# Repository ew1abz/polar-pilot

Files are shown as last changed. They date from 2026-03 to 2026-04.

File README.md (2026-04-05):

# Polar Pilot

<p align="center">
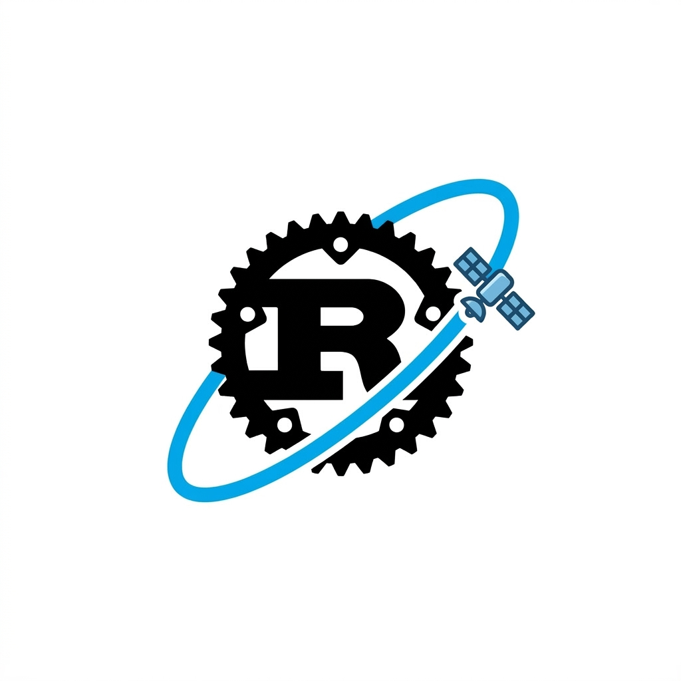
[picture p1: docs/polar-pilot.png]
Polar Pilot logo
  
</p>

<p align="center">
  <em>Bare-metal Rust firmware for a satellite antenna rotator controller — Hamlib + EasyComm II over Ethernet, live polar display, no OS.</em>
</p>

<p align="center">
  
  
  
  
</p>

<p align="center">
  <a href="https://github.com/ew1abz/polar-pilot">
    Repo card
  </a>
</p>

---

## Overview

Polar Pilot was originally designed as a controller for the
[SatNOGS rotator](https://wiki.satnogs.org/SatNOGS_Rotator_v3) — the
open-source satellite antenna rotator from the Libre Space Foundation. It has
since grown into a general-purpose two-axis rotator controller.

Polar Pilot turns an STM32L432KC Nucleo-32 board into a full-featured antenna
rotator controller. It speaks both **Hamlib rotctld** (TCP port 4533) and
**EasyComm II** (USART2 serial) so it integrates directly with
[gpredict](http://gpredict.oz9aec.net/), [Orbitron](https://www.stoff.pl/),
or any rotator-aware logging software out of the box.

Networking is handled by a W5500 hardwired TCP/IP module over SPI. A 128×64
OLED shows a live polar diagram of current and target azimuth/elevation. A
5-way navigation button lets you jog the rotator manually without a computer.

The entire firmware is `no_std` / `no_main` — no RTOS, no heap, no Linux. Nine
concurrent async tasks run on the [Embassy](https://embassy.dev/) executor.

## Features

- **Dual interface** — Ethernet (TCP :4533) and serial (USART2) operate simultaneously
- **Dual serial protocol** — EasyComm II and GS-232/GS-232B commands on the same USART2 port
- **Dual TCP connection** — up to two concurrent rotctld clients on port 4533
- **W5500 Ethernet** — ICMP (ping), DHCP, hardwired TCP/IP stack
- **[SSD1306 polar display](docs/OLED_POLAR_DISPLAY.md)** — real-time azimuth/elevation polar chart at 4 Hz
- **Stepper motor control** — hardware PWM via TIM1/TIM2, STEP/DIR/EN interface
- **[Auto-homing](docs/HOMING.md)** — endstop-based homing on power-on
- **Soft limits** — configurable AZ/EL travel limits via rotctld (`L`) and EasyComm (`LM`), persisted across commands
- **[5-way joystick](docs/MANUAL_CONTROL.md)** — manual GoTo and Stop commands without a PC
- **Heartbeat LED** — 1 Hz blink on PB3 to confirm the firmware is alive
- **Embassy async** — nine cooperative tasks, no RTOS, no heap

## Hardware

The firmware is flexible — W5500, SSD1306, stepper drivers, and the 5-way
button can each be omitted. The system boots and operates with whatever subset
is physically connected; missing peripherals are detected at runtime and their
tasks degrade gracefully without affecting the rest.

| Component | Part | Required | Notes |
|---|---|---|---|
| MCU | STM32L432KC | Yes | Cortex-M4F, 80 MHz, 256 KB flash |
| Board | Nucleo-L432KC  | Yes | Nucleo-32, ST-Link v2 onboard |
| Ethernet | W5500 module | No | Rotctld TCP server disabled if absent |
| Display | SSD1306 | No | 128×64 OLED, I2C; retries until connected |
| AZ stepper | A4988 or equiv | Yes | STEP/DIR/EN |
| EL stepper | A4988 or equiv | Yes | STEP/DIR/EN |
| Navigation | 5-way button | No | Pull-ups hold idle if unplugged  |
| Endstops | Microswitch ×2 | Yes | Homing faults without them |

### Required Nucleo board modifications

Four 0 Ω solder bridges must be removed before assembling:

| Bridge | Why |
|---|---|
| SB1 | Frees PC14 from the 32 kHz oscillator -> AZ DIR output |
| SB2 | Frees PC15 from the 32 kHz oscillator -> Nav CENTER input |
| SB16 | Isolates PA5 from PB6 so SPI1 (W5500) and I2C1 (SSD1306) don't short |
| SB18 | Isolates PA6 from PB7 for the same reason |

See [docs/SPEC.md](docs/SPEC.md) for the full pin table and a standalone-power
jumper note (needed when running without USB).

### Schematic

The KiCad schematic is in [kikad/polar-pilot.kicad_sch](kikad/polar-pilot.kicad_sch).
A rendered PDF export is at [kikad/polar-pilot.pdf](kikad/polar-pilot.pdf).

## Getting Started

### Prerequisites

```bash
rustup target add thumbv7em-none-eabihf
cargo install probe-rs-tools
```

### Build and flash

```bash
cargo build --release        # build only
cargo run --release          # build + flash + RTT console
```

### Hardware test binaries

```bash
cargo run --release --bin w5500_test    # W5500 chip version register
cargo run --release --bin oled_test     # OLED display
cargo run --release --bin motor_test    # stepper motion
cargo run --release --bin endstop_test  # endstop inputs
cargo run --release --bin button_test   # 5-way nav buttons
```

### Connecting gpredict

1. Flash the firmware and connect the W5500 module to your network.
2. Watch the LCD for the DHCP-assigned IP address.
3. In gpredict → Edit → Preferences → Interfaces → Rotators, add a new
   rotator: **Host** = `<ip>`, **Port** = `4533`.
4. Start tracking — gpredict will drive the rotator via rotctld protocol.

## Architecture

Nine Embassy async tasks communicate through two shared primitives:

```text
[rotctld TCP :4533] ──┐
[easycom USART2]  ────┤  RotatorCmd   ┌────────────┐
[5-way nav keys]  ────┴──────────────►│ motor_task ├──► Watch<RotatorState>
                                      └────────────┘
                                            │
                        ┌───────────────────┼───────────────┐
                        ▼                   ▼               ▼
                  display_task        ethernet_task      led_task
```

- **`Watch<RotatorState>`** — single-producer (motor_task), multi-consumer
  broadcast of current and target position
- **`Channel<RotatorCmd>`** — multi-producer (rotctld, easycom, keys),
  single-consumer (motor_task) command funnel

Full data-flow diagrams and per-task peripheral assignments are in
[docs/TASK_ARCHITECTURE.md](docs/TASK_ARCHITECTURE.md).

## Quality

**Memory-safe by construction.** Written in Rust — no buffer overflows, no
use-after-free, no data races. `#![no_std]` / `#![no_main]` with zero heap
allocation; every buffer is stack or statically allocated, so there is no
allocator to corrupt and no fragmentation at runtime.

**Tested at two layers.** A suite of 52 protocol tests runs against an
in-process Python stub on every CI push — no hardware required. A separate
live test suite covers DHCP/TCP connectivity, motor convergence, soft-limit
enforcement, EasyComm II, GS-232, and two concurrent TCP clients against real
hardware before every release.

**Automated CI/CD.** GitHub Actions builds the firmware on every push.
A dedicated release workflow fires on a version tag, produces `.bin` and
`.hex` artifacts, and publishes them to the GitHub Releases page automatically.

**Comprehensive documentation.**

| Document | Contents |
|---|---|
| [docs/SPEC.md](docs/SPEC.md) | Full pin table, solder-bridge modifications, protocol reference |
| [docs/TASK_ARCHITECTURE.md](docs/TASK_ARCHITECTURE.md) | Per-task data flow and peripheral assignments |
| [docs/HOMING.md](docs/HOMING.md) | Homing algorithm, fault handling, edge cases |
| [docs/MANUAL_CONTROL.md](docs/MANUAL_CONTROL.md) | 5-way joystick behaviour |
| [docs/OLED_POLAR_DISPLAY.md](docs/OLED_POLAR_DISPLAY.md) | Polar chart rendering |
| [docs/BOM.md](docs/BOM.md) | Bill of materials with datasheets and purchase links |
| [docs/DEVELOPMENT.md](docs/DEVELOPMENT.md) | Build, flash, test, and crate dependency notes |
| [docs/RELEASE_CHECKLIST.md](docs/RELEASE_CHECKLIST.md) | Step-by-step release process |
| [kikad/polar-pilot.pdf](kikad/polar-pilot.pdf) | Full schematic (KiCad PDF export) |

## Roadmap

- [ ] [540° / 1.5-rotation overtravel mode](docs/OVERTRAVEL.md) (eliminates the north-crossing dead zone)
- [ ] Single-axis (AZ-only) build via a Cargo feature flag
- [ ] Auxiliary GPIO outputs for LNA, PA, and antenna switch control
- [ ] Screen modes: polar chart / big AZ+EL digits / info (IP, version, GitHub)
- [ ] Rust TUI companion application
- [ ] Rust/WASM web companion app
- [ ] Firmware update over the network (OTA via TCP)
- [ ] RP2350 port using a board with integrated W5500
- [ ] Custom PCB with integrated PoE

## License

Copyright (C) 2026 ew1abz

This program is free software: you can redistribute it and/or modify it under
the terms of the **GNU General Public License v3.0** as published by the Free
Software Foundation.

See [LICENSE](LICENSE) for the full text.

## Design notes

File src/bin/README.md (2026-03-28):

# Hardware Tests

Standalone binaries for testing individual peripherals on the STM32L432KC
Nucleo-32 board. Each test is self-contained — no dependencies between them.

## Prerequisites

```bash
rustup target add thumbv7em-none-eabihf
cargo install probe-rs-tools
```

Connect the Nucleo board via USB. Output is via RTT (Real-Time Transfer)
shown in the `cargo run` terminal.

## Tests

### button_test — 5-way navigation switch

Polls all 5 buttons at 20 ms and logs press/release events.
LED turns on while any button is held.

**Pins**: UP=PB1, DOWN=PB0, LEFT=PA11, RIGHT=PA12, CENTER=PC15
(active-low, internal pull-up)

```bash
cargo run --release --bin button_test
```

### motor_test — AZ/EL stepper motors

Asserts motor enable (PB4 low), then drives both steppers via hardware PWM.
Toggles direction on both axes every 2 seconds. LED blinks as heartbeat.

**Pins**: AZ STEP=PA8 (TIM1), EL STEP=PA0 (TIM2), AZ DIR=PC14, EL DIR=PA9,
Motor EN=PB4 (active-low)

```bash
cargo run --release --bin motor_test
```

### oled_test — SSD1306 128x64 OLED display

Initializes the SSD1306 over I2C1, then draws a title ("Polar Pilot"),
a counter incrementing every second, and a dot cycling through 4 corners.
LED toggles each update.

**Pins**: I2C1 — PB6/SCL, PB7/SDA (address 0x3C)

```bash
cargo run --release --bin oled_test
```

### endstop_test — AZ/EL homing with endstops

Drives both steppers at 200 Hz toward home. When an endstop
triggers (active-low), that axis stops. LED blinks fast once
both axes are homed. Skips axes already at home on startup.

**Pins**: AZ STEP=PA8 (TIM1), EL STEP=PA0 (TIM2), AZ DIR=PC14,
EL DIR=PA9, Motor EN=PB4 (active-low), AZ Home=PA10, EL Home=PB5
(active-low, pull-up)

```bash
cargo run --release --bin endstop_test
```

### w5500_test — W5500 SPI Ethernet

Resets the W5500 via PA1, then reads the VERSIONR register over SPI1.
Expects `0x04`. Logs attempt count and blinks LED fast on success.

**Pins**: SPI1 (PA5/SCK, PA6/MISO, PA7/MOSI, PA4/CS), RST=PA1

```bash
cargo run --release --bin w5500_test
```

## Adding a new test

Create `src/bin/<name>.rs` with `#![no_std]`, `#![no_main]`, and an
`#[embassy_executor::main]` entry point. It will be picked up automatically
by Cargo as a separate binary target.

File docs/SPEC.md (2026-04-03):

# STM32L432 + W5500 Antenna Rotator Controller

## Overview

Bare-metal Rust firmware ("Polar Pilot") for a two-axis antenna rotator
controller. Runs on an STM32L432 Nucleo-32 board with a W5500 SPI Ethernet
module, SSD1306 OLED display, two stepper motor drivers, a 5-way navigation
button, and two homing endstops. Supports Hamlib rotctld (TCP :4533) and
EasyComm II (USART2 serial), with a polar-chart local display and automatic
homing on power-on.

## Hardware

| Component | Part | Notes |
|---|---|---|
| MCU | STM32L432KC | Cortex-M4F, 80 MHz, 256 KB flash |
| Board | Nucleo-L432KC | Nucleo-32 form factor, ST-Link v2  |
| Ethernet | W5500 | Hardwired TCP/IP, SPI interface |
| Display | SSD1306 | 128×64 OLED, I2C |
| AZ stepper | A4988 or similar | STEP/DIR/EN interface |
| EL stepper | A4988 or similar | STEP/DIR/EN interface |
| Navigation | 5-way button | UP/DOWN/LEFT/RIGHT/CENTER |
| Endstops | Microswitch ×2 | Active-low, internal pull-up |

### Pin Assignments

Four 0 Ω resistors on the Nucleo board must be removed:

| Resistor | Default | Connects | Why remove |
|---|---|---|---|
| SB1 | ON | PC14 to OSC | Free PC14 for AZ DIR (no 32k LSE) |
| SB2 | ON | PC15 to OSC | Free PC15 for Nav CENTER (no LSE) |
| SB16 | ON | PA5 ↔ PB6 | Isolate SPI1_SCK from I2C1_SCL |
| SB18 | ON | PA6 ↔ PB7 | Isolate SPI1_MISO from I2C1_SDA |

SB16/SB18 bridge the SPI1 and I2C1 pins. Without removing them, SPI1 (W5500)
and I2C1 (SSD1306) cannot operate simultaneously. See UM1956 §7.10.

| Pin  | Label | Function | Peripheral | Notes |
|---|---|---|---|---|
| PA0  | A0 | EL STEP | TIM2_CH1 | HW pulse generation |
| PA1  | A1 | W5500 RST  | GPIO output  | |
| PA3  | A2 | W5500 INT  | EXTI3 | |
| PA4  | A3 | SPI1 CS | GPIO output  | W5500 chip select |
| PA5  | A4 | SPI1 SCK | SPI1 | W5500 |
| PA6  | A5 | SPI1 MISO  | SPI1 | W5500 |
| PA7  | A6 | SPI1 MOSI  | SPI1 | W5500 |
| PA2  | A7 | USART2 TX  | USART2 (AF7) | ST-LINK virtual COM |
| PA10 | D0 | AZ Home | GPIO input | Pull-up, active-low endstop |
| PA9  | D1 | EL DIR | GPIO output  | |
| PA12 | D2 | Nav RIGHT  | GPIO input | Pull-up |
| PB0  | D3 | Nav DOWN | GPIO input | Pull-up |
| PB7  | D4 | I2C1_SDA | I2C1 | SSD1306 display |
| PB6  | D5 | I2C1_SCL | I2C1 | SSD1306 display |
| PB1  | D6 | Nav UP | GPIO input | Pull-up |
| PC14 | D7 | AZ DIR | GPIO output  | |
| PC15 | D8 | Nav CENTER | GPIO input | Pull-up |
| PA8  | D9 | AZ STEP | TIM1_CH1 | HW pulse generation |
| PA11 | D10 | Nav LEFT | GPIO input | Pull-up |
| PB5  | D11 | EL Home | GPIO input | Pull-up, active-low endstop |
| PB4  | D12 | Motor EN | GPIO output  | Shared stepper EN, active-low |
| PB3  | D13 | Heartbeat  | GPIO output  | Onboard LED (LD3) |
| PA15 | — | USART2 RX  | USART2 (AF3) | ST-LINK VCP, not on headers |

**Peripherals used:** SPI1 (W5500), I2C1 (SSD1306), USART2 (serial/EasyComm),
TIM1 (AZ step), TIM2 (EL step), TIM15 (Embassy time driver), RNG,
DMA1_CH2/CH3 (SPI RX/TX), DMA1_CH6/CH7 (USART2 RX/TX).

### Standalone Operation (No USB)

When powered from an external 3.3 V supply without a USB cable, the ST-LINK
section is unpowered and its nRST output holds the MCU in reset indefinitely.

**Fix**: bridge **CN2 pin 4** (ST-LINK VDD, 3.3 V) to **CN4 pin 14** (main
3.3 V rail) with a jumper wire. This keeps the ST-LINK powered, releases
nRST, and the MCU boots normally without USB.

> CN2 is the 4-pin SWD debug connector; CN4 is the right-side morpho header.

## Software Architecture

### Tasks

See `docs/TASK_ARCHITECTURE.md` for detailed data flow diagrams and
per-task peripheral assignments. Summary:

1. **main** — Inits clocks (80 MHz), peripherals, spawns all tasks, then idles.
2. **ethernet_task** — Pumps W5500 SPI driver (embassy-net-wiznet Runner).
3. **net_task** — Drives TCP/IP stack (DHCP, ARP, timers).
4. **dhcp_watchdog_task** — Waits 120 s for DHCP; falls back to static IP.
5. **motor_task** — Receives commands, slews steppers via TIM1/TIM2 PWM,
   runs homing sequence on power-on, publishes state.
6. **display_task** — Renders polar diagram + status on SSD1306 OLED at 4 Hz.
7. **key_task** — Debounces 5-way nav buttons at 20 ms, sends GoTo/Stop commands.
8. **rotctld_task** — TCP server on :4533, Hamlib rotctld protocol subset.
9. **easycom_task** — USART2 serial, EasyComm II protocol.
10. **led_task** — PB3 heartbeat at 1 Hz.

### Network Configuration

- **DHCP client**: Enabled. Falls back to static IP after 120 s if no offer arrives.
- **Static fallback**: `192.168.1.200/24`, gateway `192.168.1.1`
  (configurable at the top of `src/tasks/net.rs`).
- **MAC address**: Locally-administered, hardcoded (`02:00:00:00:00:01`).
- **Listen port**: 4533 (TCP).

## Rotctld Protocol (Hamlib)

The device implements a subset of the rotctld text protocol. Each command is
a single line terminated by `\n`. Responses are also newline-terminated.

Up to **2 concurrent TCP clients** are supported simultaneously on port 4533.

### Supported Commands

| Command | Alias | Description | Response |
|---|---|---|---|
| `p` | `\get_pos` | Get position | `<az>\n<el>\n` |
| `P <az> <el>` | `\set_pos <az> <el>` | Set position | `RPRT 0\n` |
| `S` | `\stop` | Stop rotation | `RPRT 0\n` |
| `l` | `\get_limits` | Get soft limits | `az_min\naz_max\nel_min\nel_max\nRPRT 0\n` |
| `L <az_min> <az_max> <el_min> <el_max>` | `\set_limits …` | Set soft limits | `RPRT 0\n` |
| `q` | `\quit` | Close connection | (connection closed) |
| `_` | `\get_info` | Get info | `Model: Polar Pilot\n` |
| `\dump_state` | — | Hamlib compatibility | State block with current limits |

When `Phase::Fault`, `p`, `P`, and `S` all respond with:

```text
FAULT: <message>
RPRT -9
```

`RPRT -9` is Hamlib's "command rejected" code. Unrecognized commands return `RPRT -1\n`.

### `\dump_state` Response

The `min_az/max_az/min_el/max_el` fields reflect the current soft limits:

```text
0
rot_model=0
min_az=<az_min>
max_az=<az_max>
min_el=<el_min>
max_el=<el_max>
0
0
```

## EasyComm II Protocol

Line endings: CR, LF, or CR+LF are all accepted.

| Command | Standard  | Description | Response |
|---|---|---|---|
| `AZ` | EasyComm  | Query position | `AZ<az> EL<el>\n` |
| `AZ<az> EL<el>` | EasyComm  | Set both axes | (none) |
| `SA` / `SE` / `SA SE` | EasyComm  | Stop AZ / EL / both | (none) |
| `LM` | EasyComm  | Get soft limits | `LM az_min az_max el_min el_max\n` |
| `LM <az_min> <az_max> <el_min> <el_max>`  | EasyComm  | Set soft limits | (none) |
| `VE` | EasyComm  | Version query | `Polar Pilot v<ver>\n` |
| `RS` | EasyComm  | Park to 0/0 (no homing)  | (none) |
| `RH` | EasyComm  | Re-home (endstop search) | (none) |
| `C` | GS-232 | Query position | `AZ<az> EL<el>\n` |
| `A<NNN>` | GS-232 | Set azimuth only | (none) |
| `E<NNN>` | GS-232 | Set elevation only | (none) |
| `W <az> <el>` | GS-232B | Set both axes | (none) |
| `?` | -- | Keep-alive | `\r` |

## Development

Build instructions, flash commands, hardware test binaries, known issues, and
the protocol test suite are documented in [docs/DEVELOPMENT.md](DEVELOPMENT.md).

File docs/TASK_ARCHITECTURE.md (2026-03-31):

# Polar Pilot — Task Architecture

## Overview

The firmware runs as a set of cooperative async tasks on the Embassy executor.
All tasks share a single thread (Cortex-M4 has no OS) and yield at `.await`
points. Communication between tasks uses lock-free Embassy synchronization
primitives.

## Shared State

### `STATE` — Watch

`Watch<CriticalSectionRawMutex, RotatorState, 4>`

Single-producer (motor_task), multi-consumer broadcast of current state.

```rust
struct RotatorState {
    target_az:  f32,   // commanded azimuth   (degrees)
    target_el:  f32,   // commanded elevation (degrees)
    current_az: f32,   // virtual position from step accumulator
    current_el: f32,   // virtual position from step accumulator
    moving:     bool,  // true while any axis is slewing
    link_up:    bool,  // (reserved, always false — IP read directly from Stack)
    phase:      Phase, // Homing | Running | Fault(&'static str)
}
```

Writers call `STATE.sender().send(state)` — non-blocking, overwrites.
Readers call `STATE.try_get()` — returns the latest value without blocking.

### `CMD` — Channel

`Channel<CriticalSectionRawMutex, RotatorCmd, 4>`

Multi-producer command funnel into motor_task.

```rust
enum RotatorCmd {
    GoTo { az: f32, el: f32 },
    Stop,
}
```

Producers: rotctld_task, easycom_task, key_task.
Consumer: motor_task (clamped to LIMITS before applying).

### `LIMITS` — Mutex

`Mutex<CriticalSectionRawMutex, Cell<SoftLimits>>`

Operator-configurable travel limits. Read by motor_task on every GoTo;
written by rotctld_task (`L`) and easycom_task (`LM`). Defaults to
AZ 0–360°, EL 0–180°. Resets to defaults on power cycle.

## Task Map

```text
                       ┌──────────────┐
                       │     main     │
                       │  (init only) │
                       └──────┬───────┘
                              │ spawns all tasks
      ┌──────┬──────┬─────────┼──────┬────────┬──────┬──────┐
      ▼      ▼      ▼         ▼      ▼        ▼      ▼      ▼
  ┌──────┐ ┌────┐ ┌──────┐ ┌──────┐ ┌──────┐ ┌────┐ ┌────┐ ┌────┐
  │motor │ │disp│ │ key  │ │rotcld│ │easyco│ │eth │ │net │ │led │
  │ task │ │ lay│ │ task │ │  task│ │m task│ │task│ │task│ │task│
  └──────┘ └────┘ └──────┘ └──────┘ └──────┘ └────┘ └────┘ └────┘
      │        ▲      │         │        │
      │ STATE  │      │   CMD   │        │   LIMITS
      ▼        │      ▼         ▼        ▼
  ┌───────┐    │  ┌──────────────────────────┐
  │ Watch │────┘  │     Command Channel      │
  │(STATE)│◄──────│       (RotatorCmd)       │
  └───────┘       └──────────────────────────┘

  Also spawned:
  ┌─────────────────┐
  │ dhcp_watchdog   │  waits 120 s, then sets static IP via Stack
  └─────────────────┘
```

## Task Descriptions

### 1. main (init only)

- Configures clocks (80 MHz HSI+PLL)
- Initializes all peripherals: SPI1, I2C1, USART2, TIM1, TIM2, GPIOs, RNG
- Creates W5500 driver, embassy-net stack
- Publishes initial `RotatorState::default()` to STATE
- Spawns all tasks, then returns (idles)

**Peripherals consumed**: all — parceled out to tasks via ownership transfer.

### 2. ethernet_task

- Runs the `embassy-net-wiznet` W5500 Runner
- Pumps SPI frames between the W5500 and the network stack

**Peripherals**: SPI1 (PA4–PA7, DMA1_CH2/CH3), W5500 INT (PA3), W5500 RST (PA1)

### 3. net_task

- Runs `embassy_net::Stack::run`
- Handles DHCP, ARP, ICMP, TCP timers

**Peripherals**: none directly (operates on the Stack)

### 4. dhcp_watchdog_task

- Calls `stack.wait_config_up()` with a 120 s timeout
- On timeout: calls `stack.set_config_v4(Static(...))` with the predefined
  fallback address (`192.168.1.200/24`)
- After resolving (either way), sleeps indefinitely

**Peripherals**: none (operates on the Stack)

### 5. motor_task

**Purpose**: homing, position tracking, stepper control.

**Homing (runs once at power-on):**

1. Publishes `Phase::Homing`
2. AZ axis: back-off if already on endstop (3 s timeout → `Fault`), then
   approach in negative direction until endstop asserts (95 s limit → `Fault`).
   Sets `current_az = 0`, `target_az = 0`.
3. EL axis: same sequence (28 s limit).
4. Publishes `Phase::Running`.

On any homing fault: disables motor driver, publishes
`Phase::Fault("AZ endstop stuck" | "AZ travel limit" | …)`, loops forever.

**Normal operation loop (1 ms tick):**

- Receives `RotatorCmd` from CMD channel (with 1 ms timeout)
- GoTo: clamps targets to LIMITS, then updates target_az/target_el
- Stop: sets targets to current position
- Advances virtual position each tick using step accumulator:
  `steps = floor(elapsed_us × STEP_HZ / 1_000_000)` — fractional remainder
  carries forward to prevent truncation drift
- Enables/disables TIM1 (AZ) and TIM2 (EL) PWM based on whether axis is moving
- Hardware endstop safety: if endstop asserts while moving toward home,
  zeroes position and stops PWM
- Software limits: AZ lower limit removed (allows wrap through north);
  AZ upper 360° and EL 0°/180° limits stop PWM and reset target
- Motor enable pin (PB4) driven low while moving, high when idle
- Publishes RotatorState every tick

**Motor parameters** (in `src/tasks/motor.rs`):

| Parameter | Value |
|---|---|
| STEP_HZ | 4000 Hz |
| STEPS_PER_REV  | 200 (full step) |
| GEAR_RATIO | 54:1 |
| AZ_MICROSTEPS  | 32 |
| EL_MICROSTEPS  | 32 |
| MOTOR_TICK | 1 ms |

**Peripherals**: TIM1 (PA8), TIM2 (PA0), GPIO out (PC14 AZ DIR, PA9 EL DIR,
PB4 motor EN), GPIO in (PA10 AZ home, PB5 EL home)

### 6. display_task

**Purpose**: render the polar diagram and status on the SSD1306 OLED.

- Receives `Stack` handle for direct IP/link-status queries via `config_v4()`
- Redraws at 4 Hz (250 ms Ticker)
- Fault screen: full-panel text (`FAULT` / message / `Power cycle` / `to reset`)
- Normal screen: polar rings, crosshair, cardinal labels (N/S/E/W),
  airplane marker at current az/el, AZ/EL readout, status, IP address
- IP shown split across two rows: `A.B.` / `C.D`, or `---.---.` / `---.---`
  while waiting for DHCP
- Status line: `Homing` / `Moving` / `Idle` / `No IP`

See [OLED_POLAR_DISPLAY.md](OLED_POLAR_DISPLAY.md) for rendering details.

**Peripherals**: I2C1 (PB6 SCL, PB7 SDA) — blocking 100 kHz

**Note**: blocking I2C flush (~92 ms per frame) is compensated by motor_task's
elapsed-time step accumulator — virtual position tracks physical motion
regardless of display task scheduling delays.

### 7. key_task

**Purpose**: read the 5-way navigation button and send commands.

- Scans 5 GPIO inputs: UP (PB1), DOWN (PB0), LEFT (PA11), RIGHT (PA12),
  CENTER (PC15)
- Debounce: 20 ms poll, require 2 consecutive identical reads
- Button actions:
  - **UP**: jog AZ positive (sentinel target +9999°, motor limits enforce stop)
  - **DOWN**: jog AZ negative (sentinel target −9999°)
  - **RIGHT**: jog EL positive (sentinel target +9999°)
  - **LEFT**: jog EL negative (sentinel target −9999°)
  - **CENTER press**: park both axes to AZ 0° / EL 0°
- Release any jog button → `RotatorCmd::Stop`
- Simultaneous AZ + EL buttons combined into one GoTo per tick
- All input ignored when `phase != Phase::Running`

**Peripherals**: GPIO input pull-up (PB1, PB0, PA11, PA12, PC15)

### 8. rotctld_task

**Purpose**: Hamlib rotctld TCP server.

- Binds TCP socket on port 4533; accepts one connection at a time
- 30 s inactivity timeout per connection
- Checks `Phase::Fault` on every command — returns `FAULT: <msg>\nRPRT -9\n`
- Supported commands: `p`/`\get_pos`, `P`/`\set_pos`, `S`/`\stop`,
  `l`/`\get_limits`, `L`/`\set_limits`, `q`/`\quit`, `_`/`\get_info`,
  `\dump_state`
- `\dump_state` reflects current LIMITS values

**Peripherals**: none (embassy-net TCP socket)

### 9. easycom_task

**Purpose**: EasyComm II serial interface.

- USART2 RX (PA15), TX (PA2) — 9600 baud, DMA
- Connected to ST-LINK VCP (appears as `/dev/ttyACM0`)
- Supported commands: `AZ`/`AZ<n> EL<n>`, `SA`/`SE`/`SA SE`, `VE`,
  `LM` (get limits), `LM <az_min> <az_max> <el_min> <el_max>` (set limits)

**Peripherals**: USART2 TX (PA2, AF7), USART2 RX (PA15, AF3),
DMA1_CH7 (TX), DMA1_CH6 (RX)

### 10. led_task

- Toggles PB3 (onboard LED) at 1 Hz as heartbeat
- `Ticker::every(Duration::from_secs(1))`

**Peripherals**: GPIO out (PB3)

## Data Flow Summary

```text
 [rotctld TCP]──┐
 [easycom UART]─┤  RotatorCmd      ┌─────────────┐  STATE   ┌──────────┐
 [5-way keys]───┴─────────────────►│ motor_task  ├─────────►│ display  │
                                   │             │          └──────────┘
                RotatorCmd         │ TIM1+TIM2   │  STATE   ┌──────────┐
  LIMITS ──────────────────────────│ endstops    ├─────────►│ rotctld  │
  (read on GoTo)                   └─────────────┘          └──────────┘
                                                   STATE   ┌──────────┐
                                                 ─────────►│ easycom  │
                                                           └──────────┘
```

- **Commands** flow in from three sources via CMD channel
- **State** flows out from motor_task via STATE watch to all readers
- **LIMITS** are written by rotctld/easycom, read by motor_task on GoTo
- **IP/link status** read directly from Stack by display_task (not via STATE)

## Resource Budget

| Resource | Usage |
|---|---|
| Flash (256 KB) | ~80–100 KB with display + networking + fonts |
| RAM (64 KB) | 1 KB OLED framebuf + ~8 KB net buffers + task stacks  |
| DMA channels | DMA1_CH2 (SPI RX), CH3 (SPI TX), CH6 (UART RX), CH7 (UART TX) |
| Timers | TIM1 (AZ step), TIM2 (EL step), TIM15 (Embassy time)  |
| I2C | I2C1 (SSD1306, 100 kHz blocking) |
| SPI | SPI1 (W5500, 1 MHz async) |
| USART | USART2 (EasyComm, 9600 baud) |
| Embassy tasks | 10 concurrent |

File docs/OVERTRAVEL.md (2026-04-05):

# 1.5 Rotation (540° Overtravel)

> **Status: Not implemented.** This is a planned feature. See the Roadmap in
> [README.md](../README.md).

## Overview

Adding overtravel (540° rotation) eliminates the "dead zone" at 0°/360° north.
High-end commercial and amateur rotators use this approach to avoid forced
unwinds during satellite passes that cross the north mark.

With a standard 360° rotator, a satellite crossing 0° north forces an
immediate full-circle unwind. With a 540° rotator (0° to 540°), that same
pass can be tracked from 350° through 0° all the way to 180° before hitting a
physical limit — cutting required unwinds significantly.

## What Needs to Change

### 1. Mechanical

- **Cable service loop** — the coax must have enough slack to handle 540° of
  twist without tensioning connectors or rubbing against sharp edges.
- **Soft limits** — azimuth range extended from `0–360°` to `0–540°`.

### 2. Firmware Logic (The Overlap)

The azimuth range maps to physical angles as follows:

| Range | Physical angle |
|---|---|
| 0° – 180° | Primary range |
| 180° – 360° | Secondary range |
| 360° – 540° | Overlap (same as 0° – 180°) |

`motor_task` needs to track raw stepper position across the 360° boundary
without wrapping, and the soft-limit enforcement must accept `max_az` up to
540°.

### 3. Host Software (Hamlib / rotctld)

gpredict does not know the rotator can go past 360° without explicit
configuration. Pass the extended range to rotctld with `-m` / `-M`:

```bash
rotctld -m 0 -M 540 -model [YOUR_MODEL_ID]
```

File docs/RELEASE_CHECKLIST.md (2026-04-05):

# Release Checklist — Polar Pilot

Steps to cut an official release. The GitHub Actions release workflow
(`release.yml`) triggers automatically on a `v*.*.*` tag push and produces
`.bin` and `.hex` artifacts. Everything before that tag is manual.

---

## 1. Code

- [ ] All planned features for this release are merged to `main`
- [ ] No `TODO` / `FIXME` comments left for known blockers
- [ ] `Cargo.toml` version bumped (`version = "x.y.z"`)
- [ ] `Cargo.lock` committed (ensure reproducible builds)

## 2. Protocol Tests (Stub)

Run the full stub suite — no hardware required:

```bash
python3 -m pytest tests/test_protocol.py -v
```

- [ ] All 52 stub tests pass

## 3. Live Hardware Tests

Flash the firmware and run against real hardware:

```bash
cargo run --release

ROTATOR_HOST=<ip> ROTATOR_PORT=/dev/ttyUSB0 \
  python3 -m pytest tests/ -v --timeout=120 --override-ini="addopts="
```

- [ ] DHCP lease acquired (or static fallback at `192.168.1.200`)
- [ ] `p` returns valid AZ/EL from a cold boot
- [ ] `P <az> <el>` drives both axes to target
- [ ] Soft limits enforced (`L` / `LM` set, out-of-range `P` clamped)
- [ ] Two concurrent TCP clients connect simultaneously on port 4533
- [ ] EasyComm II commands work over USART2 (`AZ`, `AZ<n> EL<n>`, `SA`, `SE`, `VE`)
- [ ] GS-232 commands work (`C`, `A<nnn>`, `E<nnn>`, `W <az> <el>`)
- [ ] Homing sequence completes on power-on (both endstops triggered)
- [ ] All live + slow tests pass

## 4. Hardware Test Binaries

Verify each peripheral individually:

```bash
cargo run --release --bin w5500_test
cargo run --release --bin oled_test
cargo run --release --bin motor_test
cargo run --release --bin endstop_test
cargo run --release --bin button_test
```

- [ ] W5500 chip version register reads correctly
- [ ] OLED polar chart renders without artifacts
- [ ] Stepper motors sweep AZ and EL
- [ ] Both endstops register active-low transitions
- [ ] All five nav buttons register correctly

## 5. Documentation

- [ ] `docs/SPEC.md` reflects current pin assignments and hardware table
- [ ] `README.md` features list matches implemented functionality
- [ ] `docs/BOM.md` part list and links are current

## 6. Tag and Push

```bash
git tag v<x.y.z>
git push origin main --tags
```

- [ ] Tag pushed — GitHub Actions `release.yml` starts automatically
- [ ] CI build passes (check Actions tab)
- [ ] Release page shows `.bin` and `.hex` artifacts attached
- [ ] Auto-generated release notes look reasonable; edit if needed

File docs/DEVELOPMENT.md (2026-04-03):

# Polar Pilot — Development Notes

## Prerequisites

```bash
rustup target add thumbv7em-none-eabihf
cargo install probe-rs-tools       # only needed for flashing
```

Python 3.10+ is required for the protocol test suite:

```bash
python3 -m pip install pytest pytest-timeout   # stub + rotctld live tests
python3 -m pip install pyserial                # EasyComm live tests only
```

## Build

```bash
cargo build --release
```

## Flash + RTT Log

```bash
cargo run --release
```

Configured via `.cargo/config.toml` to call `probe-rs run --chip STM32L432KCUx`.

## Hardware Test Binaries

Standalone binaries in `src/bin/` exercise individual peripherals in isolation.
Flash them the same way as the main firmware:

```bash
cargo run --release --bin w5500_test    # W5500 chip version + link status
cargo run --release --bin button_test   # 5-way nav button read-out
cargo run --release --bin motor_test    # stepper sweep
cargo run --release --bin oled_test     # OLED polar chart render
cargo run --release --bin endstop_test  # endstop state over RTT
```

## Testing

### Overview

There are two testing layers:

| Layer | Runs in | Requires hardware |
|---|---|---|
| Protocol tests (`tests/test_protocol.py`) | CI and locally | No |
| Live hardware tests (`tests/test_live.py`) | Manually, pre-release | Yes |

The protocol tests run against an in-process Python TCP stub (`tests/stub_server.py`)
that mirrors the firmware's rotctld dispatch table.  The stub's state is a plain
Python object set directly in each test fixture — no sleeping, no timing, no motor
physics.

### Running Protocol Tests (Stub)

```bash
python3 -m pytest                         # uses pytest.ini defaults (excludes live tests)
python3 -m pytest tests/test_protocol.py  # explicit
```

52 tests covering all commands, argument errors, protocol robustness
(pipelining, split TCP segments, CRLF line endings, oversized lines).

### Running Live Hardware Tests

Set `ROTATOR_HOST` to the device's IP address (DHCP-assigned or static fallback
`192.168.1.200`):

The default `pytest.ini` excludes live tests with `-m "not live"`.  Pass
`-m live` (or `-m "live or slow"` to include motor-movement tests) to
override it:

```bash
# rotctld (TCP)
ROTATOR_HOST=192.168.1.42 python3 -m pytest tests/test_live.py -v --timeout=60 -m live

# EasyComm II (serial) -- requires pyserial and a USB-serial adapter on USART2
ROTATOR_PORT=/dev/ttyUSB0 python3 -m pytest tests/test_easycom.py -v --timeout=60 -m live

# Include slow motor-movement tests
ROTATOR_HOST=192.168.1.42 python3 -m pytest tests/test_live.py -v --timeout=60 -m "live or slow"

# Both together
ROTATOR_HOST=192.168.1.42 ROTATOR_PORT=/dev/ttyUSB0 python3 -m pytest tests/ -v --timeout=60 -m "live or slow"

# All 87 tests (stub + live + slow) -- overrides the default -m "not live" in pytest.ini
ROTATOR_HOST=192.168.1.42 ROTATOR_PORT=/dev/ttyUSB0 python3 -m pytest tests/ -v --timeout=120 --override-ini="addopts="

# List all tests without running them
python3 -m pytest tests/ --collect-only -q --override-ini="addopts="
```

Live tests cover DHCP/TCP connectivity, motor convergence to target, stop
response, reset/park, soft limit enforcement, and two concurrent clients.

### Test File Layout

```text
tests/
  stub_server.py      in-process TCP stub + RotatorState
  conftest.py         conn_stub (per-test clean state) and conn_live fixtures
  test_protocol.py    52 protocol tests against stub
  test_live.py        hardware tests, skipped unless ROTATOR_HOST is set
pytest.ini            marks live/slow; excludes live tests from default run
```

### Notes on Protocol Behaviour Under Test

- **Unknown commands** return `RPRT -8` (RIG_ENIMPL).
- **Invalid arguments** (wrong count, non-numeric) return `RPRT -1` (RIG_EINVAL).
- **`w`/`\send_cmd`** returns `RPRT -1` — no backend pass-through target exists.
- **Empty or whitespace-only lines** return `RPRT -8` and do not crash the server.
- **`P` with out-of-limit coordinates** is silently clamped by `motor_task` —
  the TCP layer returns `RPRT 0` and the motor stops at the limit.
- **Line buffer** is 128 bytes; lines longer than this close the connection.

## Crate Dependencies

| Crate | Purpose |
|---|---|
| `embassy-executor` | Async task executor |
| `embassy-stm32` | HAL for STM32L4 (SPI, I2C, GPIO, …) |
| `embassy-time` | Timekeeping (TIM15 driver, Ticker) |
| `embassy-sync` | Watch + Channel + Mutex for inter-task comms |
| `embassy-net` | TCP/IP stack (TCP, DHCPv4) |
| `embassy-net-wiznet` | W5500 driver for embassy-net |
| `embedded-hal-bus` | SPI ExclusiveDevice wrapper |
| `embedded-io-async`  | Async I/O traits (Write::write_all) |
| `ssd1306` | SSD1306 OLED driver |
| `embedded-graphics`  | 2D drawing primitives for OLED |
| `heapless` | Fixed-capacity String/Vec (no alloc) |
| `libm` | Software float math (sinf, cosf) |
| `defmt` + `defmt-rtt`| Logging via RTT (non-blocking) |
| `panic-reset` | Reset on panic — safe for standalone |
| `static_cell` | One-time `'static` init for task data  |
| `cortex-m` / `cortex-m-rt` | Runtime + vector table |

## Binary Size

Release build (`opt-level = "s"`, LTO):

| Configuration | .text (bytes) | Delta |
|---|---|---|
| Minimal (TCP + static IP, no defmt)  | 42,312 | baseline |
| Minimal (TCP + static IP, defmt) | 66,384 | +24,072 (+56.9%) |
| + DHCP | 75,672 | +33,360 (+78.8%) |
| + DHCP + ICMP echo reply | 78,112 | +35,800 (+84.6%) |

STM32L432KC has 256 KB flash. The `minimal` branch has static-IP-only builds
for reference.

## Project Structure

```text
.
├── .cargo/config.toml              # target, runner, DEFMT_LOG
├── .github/workflows/ci.yml        # CI: build + protocol tests
├── build.rs                        # memory.x linker script setup
├── memory.x                        # Flash/RAM layout for STM32L432
├── Cargo.toml
├── pytest.ini
├── tests/                          # rotctld protocol test suite (Python)
├── src/
│   ├── main.rs                     # peripheral init, task spawning
│   ├── types.rs                    # RotatorState, RotatorCmd, Phase, SoftLimits, statics
│   ├── util.rs                     # parse_f32, parse_f32_bytes, line helpers
│   ├── tasks/
│   │   ├── motor.rs                # motor_task — homing, slewing, endstops
│   │   ├── display.rs              # display_task — SSD1306 polar chart
│   │   ├── keys.rs                 # key_task — 5-way button
│   │   ├── rotctld.rs              # rotctld_task — TCP :4533
│   │   ├── easycom.rs              # easycom_task — USART2 EasyComm II
│   │   └── net.rs                  # ethernet_task, net_task, led_task, dhcp_watchdog_task
│   └── bin/                        # standalone hardware test binaries
│       ├── w5500_test.rs
│       ├── button_test.rs
│       ├── motor_test.rs
│       ├── oled_test.rs
│       └── endstop_test.rs
├── docs/
│   ├── SPEC.md                     # hardware spec and protocol reference
│   ├── DEVELOPMENT.md              # this file
│   ├── TASK_ARCHITECTURE.md        # task data flow and peripheral map
│   ├── OLED_POLAR_DISPLAY.md       # OLED rendering details
│   ├── HOMING.md                   # homing algorithm and fault handling
│   ├── MANUAL_CONTROL.md           # 5-way button behaviour
│   ├── MIGRATION_NOTES.md          # comparison with rust-l432-rotator
│   ├── TODO.md                     # known gaps and planned work
│   └── EEPROM_EMULATION.md         # (future) persistent configuration
```

## Known Issues & Workarounds

### STM32L432 Fixed DMA Channel Mapping

The STM32L432 has no DMAMUX — DMA channels are hardwired per peripheral.
SPI1 must use DMA1_CH2 (RX) and DMA1_CH3 (TX); USART2 must use DMA1_CH7 (TX)
and DMA1_CH6 (RX). Using wrong channels causes silent failures.

## Constraints & Decisions

- **No `std`** — bare-metal `#![no_std]`, `#![no_main]`.
- **No heap** — all buffers are stack-allocated or static.
- **Single TCP connection** — the W5500 has 8 sockets but one is sufficient
  for rotctld; keeps the code simple.
- **No TLS** — rotctld is plaintext.

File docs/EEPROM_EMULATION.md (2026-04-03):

# EEPROM Emulation — Persistent Configuration Storage

## Status: Potential Feature

## Motivation

The rotator currently loses all configuration on power cycle. Persisting the
following would improve usability:

- Park position (AZ/EL degrees)
- Soft limits (min/max AZ, min/max EL)
- Network config override (static IP, port)
- Steps-per-degree calibration for each axis
- Last known position (for resume without homing)

## Hardware Constraints

The STM32L432KC has **no dedicated data EEPROM**. The L432 only has 256 KB of
main flash, organized as 2 KB pages. Flash endurance is ~10,000 erase cycles
per page (datasheet §3.10).

Embassy-stm32's `Flash` driver implements the `embedded-storage` `NorFlash`
and `ReadNorFlash` traits, which provides the foundation for emulation.

## Solution: `sequential-storage` on Main Flash

[`sequential-storage`](https://crates.io/crates/sequential-storage) is a
`no_std`, heap-free crate that provides a wear-leveled key-value map on top of
any `NorFlash` implementation. It distributes writes across a configurable
range of flash pages so no single page absorbs all the erase cycles.

### Flash Layout

Allocate the last 4 pages (8 KB) of flash for storage, keeping them out of
the linker's program region:

```text
0x0800_0000  ┌──────────────────────┐
             │  Firmware (≤248 KB)  │
0x0803_E000  ├──────────────────────┤  ← storage start
             │  Page 62  (2 KB)     │
             │  Page 63  (2 KB)     │
             │  Page 64  (2 KB)     │
             │  Page 65  (2 KB)     │
0x0804_0000  └──────────────────────┘  ← end of flash
```

Reserve those pages in `memory.x` so the linker never places code there:

```text
/* memory.x */
MEMORY
{
  FLASH : ORIGIN = 0x08000000, LENGTH = 248K   /* was 256K */
  STORAGE : ORIGIN = 0x0803E000, LENGTH = 8K
  RAM   : ORIGIN = 0x20000000, LENGTH = 48K
}
```

### Dependencies

```toml
# Cargo.toml
[dependencies]
sequential-storage = { version = "4", default-features = false }
embedded-storage = "0.3"
```

### Key Definitions

Define all storable keys as a compact enum. Each variant serializes to a
single `u8` discriminant — the key used in the flash map.

```rust
#[repr(u8)]
#[derive(Clone, Copy, PartialEq, Eq)]
pub enum CfgKey {
    ParkAz      = 0,
    ParkEl      = 1,
    MinAz       = 2,
    MaxAz       = 3,
    MinEl       = 4,
    MaxEl       = 5,
    StepsPerDegAz = 6,
    StepsPerDegEl = 7,
    LastAz      = 8,
    LastEl      = 9,
}
```

Values are stored as raw `f32` bytes (4 bytes each).

### Storage Helper

```rust
use embassy_stm32::flash::{Flash, WRITE_SIZE};
use sequential_storage::map;

const STORAGE_RANGE: core::ops::Range<u32> = 0x0803_E000..0x0804_0000;

/// Read one f32 config value; returns `default` if not yet written.
pub async fn cfg_read(flash: &mut Flash<'_>, key: CfgKey, default: f32) -> f32 {
    let mut buf = [0u8; 4];
    match map::fetch_item::<_, _, _>(
        flash,
        STORAGE_RANGE.clone(),
        &mut [0u8; 64],   // scratch buffer
        key as u8,
        &mut buf,
    )
    .await
    {
        Ok(Some(bytes)) => f32::from_le_bytes(bytes.try_into().unwrap_or([0u8; 4])),
        _ => default,
    }
}

/// Write one f32 config value.
pub async fn cfg_write(flash: &mut Flash<'_>, key: CfgKey, value: f32) {
    let bytes = value.to_le_bytes();
    map::store_item::<_, _, _>(
        flash,
        STORAGE_RANGE.clone(),
        &mut [0u8; 64],   // scratch buffer
        key as u8,
        &bytes,
    )
    .await
    .ok();  // best-effort; log via defmt in production
}
```

### Integration with motor_task

Load calibration at startup before spawning the motor task:

```rust
// In main(), after Flash is initialized:
let mut flash = Flash::new(p.FLASH, Irqs);

let steps_az = cfg_read(&mut flash, CfgKey::StepsPerDegAz, 400.0).await;
let steps_el = cfg_read(&mut flash, CfgKey::StepsPerDegEl, 400.0).await;
let park_az  = cfg_read(&mut flash, CfgKey::ParkAz, 0.0).await;
let park_el  = cfg_read(&mut flash, CfgKey::ParkEl, 0.0).await;

spawner.spawn(motor_task(/* ... */ steps_az, steps_el, park_az, park_el)).unwrap();
```

Save position periodically from motor_task (e.g., after each completed slew):

```rust
// Inside motor_task, after slew completes:
cfg_write(&mut flash, CfgKey::LastAz, state.az).await;
cfg_write(&mut flash, CfgKey::LastEl, state.el).await;
```

### Sharing Flash Between Tasks

`embassy-stm32`'s Flash is not `Send`-shareable by default. Options:

1. **Single owner** — pass flash into a dedicated `config_task` and send
   read/write requests via a small channel. Simplest and safest.
2. **Mutex** — wrap in `embassy_sync::mutex::Mutex<CriticalSectionRawMutex, Flash>`,
   share via static. Works but flash ops block interrupt-driven tasks briefly.

Option 1 is recommended for this project since config changes are infrequent.

## Wear Budget

With 4 pages and `sequential-storage`'s wear leveling, each logical key-value
write consumes roughly `1 / (page_count × items_per_page)` of the total erase
budget. At 10,000 cycles × 4 pages and ~10 bytes per entry:

- ~3,200 items per erase cycle sweep
- A write every 10 seconds → **>10 years** before page exhaustion

Writing `LastAz`/`LastEl` after every 100 ms position tick would exhaust flash
in ~1 year — write only on slew completion or on idle timeout.

## Open Questions

- Should static IP config be in flash or hardcoded / provisioned via serial?
- Is resume-without-homing safe? (Position could be stale after manual
  movement with power off.)
- The `Flash` peripheral conflicts with in-application firmware update (IAP)
  — if OTA is added later, the storage region layout must be coordinated.

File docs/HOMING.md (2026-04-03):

# Polar Pilot — Homing Procedure

## Purpose

Homing establishes the zero-degree reference for both axes using active-low
endstop switches. Until homing completes, reported positions are meaningless
and `GoTo` commands are rejected. The `Phase` field in `RotatorState` signals
the current state to all consumers (display, rotctld, easycom).

## When Homing Runs

| Trigger | Description |
|---|---|
| **Power-on** | Runs automatically before any command is accepted |
| **Long-press CENTER** (>500 ms) | Operator-initiated re-home from `key_task` |

Re-homing sends a dedicated `RotatorCmd::Home` (to be added alongside
`GoTo`/`Stop`). `motor_task` drops any in-progress slew and restarts the
sequence.

## Phase Enum

```rust
pub enum Phase {
    Homing,   // homing in progress — commands queued but not executed
    Running,  // homed and operational
}
```

Published in every `RotatorState` send so all tasks can react.

## Axis Sequence

Axes are homed **serially**: AZ first, then EL. Both axes use identical logic.

```text
Phase::Homing published ──────────────────────────────────────────────────►
                                                            Phase::Running
  ┌──────────────┐   ┌──────────────┐   ┌──────────────┐
  │  Pre-check   │──►│   Approach   │──►│    Settle    │
  │  (back-off   │   │  (seek home) │   │  zero pos.   │
  │   if stuck)  │   │              │   │  disable PWM │
  └──────────────┘   └──────────────┘   └──────────────┘
        │ stuck?             │ limit?
        ▼                    ▼
   HomingError          HomingError
```

## Algorithm

### 1. Pre-check

Sample the endstop. If already asserted (switch closed, pin low):

- Drive the axis in the **positive direction** for a fixed back-off distance
  (10° equivalent steps) at homing speed.
- Re-sample the endstop.
- If still asserted → fault: `HomingError::EndStopStuck`. Disable motor,
  publish `Phase::Homing` with error, loop forever displaying the fault.

### 2. Approach

Drive the axis in the **negative direction** (toward home) at homing speed:

- Each `MOTOR_TICK` interval: sample the endstop, publish current state with
  `Phase::Homing`.
- When the endstop asserts → go to Settle.
- Track accumulated travel from the start position. If it exceeds
  `MAX_HOMING_TRAVEL` (AZ: 380°, EL: 100°) without the switch asserting →
  fault: `HomingError::LimitExceeded`.

### 3. Settle

- Stop PWM immediately.
- Set `current_az` / `current_el` to `0.0`.
- Set `target_az` / `target_el` to `0.0`.
- Disable motor driver (`motor_en` high).
- Proceed to the next axis (or transition to `Phase::Running` after EL).

## Parameters

| Parameter | AZ | EL | Notes |
|---|----|----|---|
| Direction to home | negative (low) | negative (low) | both axes home toward zero |
| Back-off distance | 10° steps | 10° steps | at homing speed |
| Homing PWM frequency | `STEP_HZ` | `STEP_HZ` | same as slewing |
| Max travel limit | 380° | 100° | abort if exceeded |
| Endstop pin | PA10 (active-low, pull-up) | PB5 (active-low, pull-up) | |

## Error Handling

| Error | Cause | `Phase::Fault` payload |
| --- | --- | --- |
| Endstop stuck | Switch closed before approach, still closed after 3 s back-off | `"AZ endstop stuck"` / `"EL endstop stuck"` |
| Travel limit exceeded | `MAX_HOMING_TRAVEL` elapsed without switch asserting | `"AZ travel limit"` / `"EL travel limit"` |

On any fault:

1. Motor driver disabled (`motor_en` high), PWM stopped.
2. `Phase::Fault(msg)` published to the `STATE` watch — all consumers react
   immediately without polling.
3. **OLED**: polar chart replaced by a full-screen fault screen:

   ```text
   !! FAULT !!
   AZ stuck
   ```

4. **rotctld TCP**: `get_pos`, `set_pos`, and `stop` all respond with:

   ```text
   FAULT: AZ stuck
   RPRT -9
   ```

   `RPRT -9` is Hamlib's "command rejected" code; the tracking client will
   surface a connection error rather than silently accepting bad data.

5. `motor_task` loops forever sleeping — fault is unrecoverable without a
   power cycle.

`key_task` already ignores all input when `phase != Phase::Running`, so
button presses during a fault are silently dropped.

## Bounce Suppression

Embassy GPIO inputs use internal pull-ups. The endstop switches are mechanical;
a single `is_low()` sample per `MOTOR_TICK` is sufficient at the default tick
rate (10 ms) because mechanical bounce settles within ~1–2 ms. No additional
debounce filter is required for the stop condition.

## Key_task Integration

`key_task` sends `RotatorCmd::Home` on long-press CENTER. While
`Phase::Homing`, `motor_task` ignores `GoTo` commands (drains the channel
without acting). `Stop` is always honoured.

## Comparison with Rotator Project

The `rust-l432-rotator` project uses the `stepper-motion` crate with typed
motor states and a blocking step loop. This project uses Embassy async PWM
(TIM1/TIM2) with `Timer::after(MOTOR_TICK).await` between endstop samples,
achieving the same algorithm without blocking the executor. The phase
information previously encoded in Rust types (`Homed`, `Pointing`, `Homing`)
is represented here as the `Phase` field in the published `RotatorState`.

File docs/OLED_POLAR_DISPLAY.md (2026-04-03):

# Polar Pilot — OLED Polar Display

## Overview

The SSD1306 128×64 OLED shows a polar diagram representing the antenna's
azimuth and elevation, with the current position indicated by an airplane icon.
This is the primary local UI for the rotator controller.

## Display Layout

```text
┌──────────────────────────────────┐  128 × 64 px
│  N                               │
│    ┌─────────┐   AZ: 045        │
│    │  ·───·  │   EL:  30        │
│  W─┤──·+·──├─E                 │
│    │  ·───·  │                   │
│    └─────────┘   Idle            │
│  S               192.168.        │
│                  1.200           │
└──────────────────────────────────┘
```

Left panel (0–78 px): polar chart. Right panel (TX=80 px): status text.

## Polar Diagram

**Constants** (in `src/tasks/display.rs`):

| Constant  | Value | Meaning |
|---|---|---|
| `CX` | 39 | Chart centre X |
| `CY` | 32 | Chart centre Y |
| `R_OUTER` | 30 | Outer ring radius (horizon) |
| `R_INNER` | 15 | Inner ring radius (45° elev.)  |

- **Outer ring** (r=30 px): horizon (EL = 0°)
- **Inner ring** (r=15 px): 45° elevation
- **Centre point**: zenith (EL = 90°)
- **Crosshair**: 1 px lines through centre, N–S and E–W
- **Cardinal labels**: `N` (0, 7), `S` (0, 57), `E` (CX+R+3, CY+3),
  `W` (CX−R−9, CY+3). N and S are on the left margin; E and W flank the ring.

## Coordinate Mapping

```text
angle_rad = az × π / 180          // 0 = North (up), clockwise
r         = R_OUTER × (1 − el / 90.0)
x         = CX + r × sin(angle_rad)
y         = CY − r × cos(angle_rad)
```

EL > 90° produces negative `r`, which naturally places the dot on the opposite
azimuth at the mirrored radius — no explicit fold-over needed.

`libm::sinf` / `libm::cosf` are used (no hardware trig on Cortex-M4 without FPU
intrinsics in `no_std`).

## Antenna Position Marker

17-pixel airplane icon: cross arms (±3 in one axis) plus 3×3 filled centre:

```text
      ·         (0,−3)
      ·         (0,−2)
  · · # # # · · (−3..+3, 0) + (−1..+1, −1/0/+1)
      ·         (0,+2)
      ·         (0,+3)
```

Pixel offsets (dx, dy) relative to computed (x, y):

```rust
const PLANE: [(i32, i32); 17] = [
                      (0, -3), (0, -2),
    (-3, 0), (-2, 0),
    (-1, -1), (0, -1), (1, -1),
    (-1,  0), (0,  0), (1,  0),
    (-1,  1), (0,  1), (1,  1),
               (2, 0), (3, 0),
                      (0,  2), (0,  3),
];
```

## Status Panel (right, TX = 80 px)

| Row  | y | Content |
|---|-----|---|
| 1 | 10  | `AZ:` + current azimuth as integer |
| 2 | 22  | `EL:` + current elevation as integer |
| 3 | 40  | Status string (see below) |
| 4 | 52  | IP first two octets (`A.B.`) |
| 5 | 62  | IP last two octets (`C.D`) |

Font: `FONT_6X10` from `embedded-graphics`.

### Status String

| `Phase` | Condition | Displayed |
|---|---|---|
| `Homing` | any | `Homing` |
| `Running` | moving | `Moving` |
| `Running` | IP assigned | `Idle` |
| `Running` | no IP yet | `No IP` |
| `Fault(msg)` | — | fault screen (see below) |

IP is queried directly from the Stack via `stack.config_v4()` — not via
`RotatorState.link_up` (which is always false).

### IP Address Display

When DHCP has completed, the IP is split across two rows:

```text
192.168.
1.200
```

While waiting for DHCP (or no IP):

```text
---.---.
---.---
```

## Fault Screen

When `Phase::Fault(msg)` is set, the entire panel is replaced:

```text
FAULT
<message>
Power cycle
to reset
```

Text positions: y = 12, 32, 50, 60. The display loops on this screen until
power is cycled — the fault is unrecoverable.

## Splash Screen

Shown for 2 seconds at boot before homing begins:

- Left 64×64 px: Rust logo (`src/rust.raw`, 1-bpp raw bitmap, `include_bytes!`)
- Right half:
  - `"Polar"` at (74, 24)
  - `"Pilot"` at (74, 38)
  - `"v<CARGO_PKG_VERSION>"` at (70, 56)

## Update Rate

4 Hz (250 ms `Ticker`). Full-buffer redraw each tick:
clear → draw chart → draw marker → draw text → `display.flush()`.

The blocking I2C flush at 100 kHz takes ~92 ms per frame. `motor_task`
compensates via its elapsed-time step accumulator (`as_micros()` + fractional
carry), so virtual position tracks physical motion regardless of display delays.

## Hardware

| Item | Detail |
|---|---|
| Display  | SSD1306 128×64, I2C addr 0x3C |
| Bus | I2C1 — PB6 (SCL), PB7 (SDA) |
| Speed | 100 kHz (blocking) |
| Buffer | 1024-byte static framebuffer |

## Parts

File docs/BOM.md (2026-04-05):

# Bill of Materials — Polar Pilot

Two-axis antenna rotator controller based on STM32L432KC + W5500 SPI Ethernet.

| # | Component | Part / Description | Qty | Datasheet | Amazon |
|---|---|---|-----|---|---|
| 1 | MCU Board | STM32L432KC Nucleo-32 | 1 | [UM1956](https://www.st.com/resource/en/user_manual/um1956-stm32-nucleo32-boards-mb1180-stmicroelectronics.pdf) | [B077GFHLFS](https://www.amazon.com/Nucleo-32-development-STM32L432KC-supports-connectivity/dp/B077GFHLFS) |
| 2 | Ethernet Module | W5500 SPI Ethernet | 1 | [W5500 Datasheet](https://docs.wiznet.io/Product/iEthernet/W5500/datasheet) | [B0CDWX9VQ5](https://www.amazon.com/dp/B0CDWX9VQ5) |
| 3 | Display | SSD1306 128×64 OLED, I2C | 1 | [SSD1306 Datasheet](https://cdn-shop.adafruit.com/datasheets/SSD1306.pdf) | [B09T6SJBV5](https://www.amazon.com/dp/B09T6SJBV5) |
| 4 | Motor Driver | A4988 Stepper Driver (×2) | 2 | [A4988 Datasheet](https://www.allegromicro.com/~/media/Files/Datasheets/A4988-Datasheet.ashx) | [B07BND65C8](https://www.amazon.com/dp/B07BND65C8) |
| 5 | Navigation | 5-way joystick nav button module | 1 | — | [B09DPMQ1F3](https://www.amazon.com/dp/B09DPMQ1F3) |
| 6 | Endstops | Microswitch, SPDT, through-hole (×2) | 2 | [Search Omron SS-5](https://omronfs.omron.com/en_US/ecb/products/pdf/en-ss.pdf) | [B07X142VGC](https://www.amazon.com/dp/B07X142VGC) |
| 7 | Enclosure | Serpac 151 BK | 1 | [Serpac 151](https://www.serpac.com/151.aspx) | [Search](https://www.amazon.com/s?k=Serpac+151+BK) |
| 8 | Prototype PCB | Perforated PCB 7×9 cm | 1 | — | [B07FFDFLZ3](https://www.amazon.com/dp/B07FFDFLZ3) |
| 9 | DC-DC Converter | Buck module (e.g. MP1584, 28 V → 3.3 V) | 1 | — | [B089GV88DK](https://www.amazon.com/dp/B089GV88DK) |
| 10 | Power Connector | Panel-mount barrel jack or terminal block | 1 | — | [B0DLKN8J7M](https://www.amazon.com/dp/B0DLKN8J7M) |
| 11 | PoE Adaptor | PoE splitter | 1 | — | [B01HMNJHII](https://www.amazon.com/dp/B01HMNJHII) |
| 12 | Standoffs | M3 hex standoffs assortment | 1 set | — | [Search](https://www.amazon.com/s?k=M3+hex+standoff+assortment) |

## Notes

- Four 0 Ω resistors must be removed from the Nucleo board (SB1, SB2, SB16, SB18) before assembly. See [SPEC.md](SPEC.md) for details.

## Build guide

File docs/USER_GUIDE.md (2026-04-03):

# Polar Pilot — User Guide

## First Power-On

1. Connect the rotator controller to your network via Ethernet.
2. Apply power. The OLED shows a splash screen for 2 seconds, then homing begins automatically.
3. Both axes drive toward their home switches. The display shows **Homing** until both axes reach zero.
4. Once homing completes, the display shows **No IP** (waiting for DHCP) or **Idle** (IP assigned).
5. The IP address appears on the bottom two lines of the display, e.g.:

   ```text
   192.168.
   1.200
   ```

If the device does not receive a DHCP address within 2 minutes, it falls back
to a static IP (`192.168.1.200` by default — ask your installer if this was
changed).

---

## Connecting from gpredict / rotctld

Point rotctld at the device IP on port **4533**:

```bash
rotctld -m 204 -r 192.168.1.200:4533
```

Then connect gpredict to that rotctld instance as usual.

---

## Manual Control (5-Way Button)

| Button | Action |
|---|---|
| UP | Jog azimuth clockwise (hold to keep moving) |
| DOWN | Jog azimuth counter-clockwise |
| RIGHT  | Jog elevation up |
| LEFT | Jog elevation down |
| CENTER | Park — move both axes to AZ 0° / EL 0° |

Buttons are ignored during homing. Normal operation resumes automatically
when homing finishes.

---

## Soft Travel Limits

Soft limits restrict where the rotator will move in response to commands
from rotctld or EasyComm. They do **not** affect manual button jogging.
Limits reset to the full range (AZ 0–360°, EL 0–180°) on every power cycle.

### Why use soft limits?

- Protect cabling that cannot reach certain positions
- Restrict elevation to your antenna's useful range (e.g. EL 5–90°)
- Keep azimuth within a sector if your installation is obstructed

### Setting limits via TCP (rotctld)

Connect with netcat or any TCP client:

```bash
nc 192.168.1.200 4533
```

**Get current limits:**

```text
l
```

Response:

```text
0.0        ← az_min
360.0      ← az_max
0.0        ← el_min
180.0      ← el_max
RPRT 0
```

**Set limits:**

```text
L <az_min> <az_max> <el_min> <el_max>
```

Examples:

```bash
# Restrict azimuth to a 180° sector (east hemisphere only)
L 90 270 0 180

# Set minimum elevation to 5° (ignore signals below horizon clutter)
L 0 360 5 180

# Reset to full range
L 0 360 0 180
```

Response: `RPRT 0` on success, `RPRT -1` on bad arguments.

### Setting limits via EasyComm (serial / USB)

Connect at **9600 baud** to the USB serial port (usually `/dev/ttyACM0` on
Linux, `COMx` on Windows).

**Get current limits:**

```text
LM
```

Response:

```text
LM 0.0 360.0 0.0 180.0
```

**Set limits:**

```text
LM <az_min> <az_max> <el_min> <el_max>
```

Examples:

```text
LM 90 270 0 180
LM 0 360 5 180
LM 0 360 0 180
```

No response is sent on success. Invalid arguments are silently ignored
(limits remain unchanged).

---

## Fault Handling

If a homing fault occurs (endstop stuck or travel limit exceeded), the display
shows:

```text
FAULT
AZ endstop stuck
Power cycle
to reset
```

All rotctld/EasyComm commands respond with `FAULT: <message>` while a fault
is active. **Power cycle the controller to recover.** Check the endstop
switches if the fault repeats.

---

## EasyComm II Quick Reference

| Command | Description |
|---|---|
| `AZ` | Query current AZ/EL position |
| `AZ<degrees> EL<degrees>` | Command a position |
| `SA` / `SE` / `SA SE` | Stop azimuth / elevation / both |
| `LM` | Get soft limits |
| `LM az_min az_max el_min el_max` | Set soft limits |
| `VE` | Query firmware version |

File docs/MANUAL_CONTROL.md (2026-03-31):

# Manual Control — 5-Way Navigation Button

## Overview

A 5-way navigation button provides direct manual jogging of the rotator axes.
Manual input works in parallel with the rotctld TCP and EasyComm II serial
interfaces — all sources drive the same command channel. Motors run only while
a direction button is held; releasing stops the axis.

## Hardware

- **5-way navigation button** — UP / DOWN / LEFT / RIGHT / CENTER.
  Active-low with internal pull-ups; debounced in firmware.

### GPIO Assignment

| Button | Pin  | Nucleo Label | Notes |
|---|---|---|---|
| UP | PB1  | D6 (CN3) | pull-up, active-low |
| DOWN | PB0  | D3 (CN3) | pull-up, active-low |
| LEFT | PA11 | D10 (CN3) | pull-up, active-low |
| RIGHT  | PA12 | D2 (CN3) | pull-up, active-low |
| CENTER | PC15 | D8 (CN3) | pull-up, active-low |

### Button Mapping

| Button | Action |
|---|---|
| UP | Jog AZ positive (while held, stops at soft limit) |
| DOWN | Jog AZ negative (while held, stops at soft limit or 0°) |
| RIGHT  | Jog EL positive (while held, stops at soft limit or 180°) |
| LEFT | Jog EL negative (while held, stops at soft limit or 0°) |
| CENTER | Park: move both axes to AZ 0° / EL 0° |

## Behaviour

### Jogging (UP / DOWN / LEFT / RIGHT)

- On press: a `GoTo` is sent each poll tick with a sentinel target of ±9999°.
  Motor_task clamps the target to the current soft limits, so the axis runs
  until it reaches the limit and stops.
- On release: `RotatorCmd::Stop` is sent; axis stops immediately.
- Simultaneous AZ + EL buttons are combined into a single `GoTo` per tick —
  both axes move concurrently.
- Opposite directions on the same axis: `up` beats `down`; `right` beats `left`
  (evaluation order in the poll loop).

### Parking (CENTER)

- A single press edge sends `GoTo { az: 0.0, el: 0.0 }`.
- Both motors slew to 0°/0° and stop when they arrive.
- Any subsequent jog press overrides the park move.

### Parallel Operation

- Manual and serial inputs share the `CMD` channel — no mode switch required.
  Last command wins.

### Phase Gate

- All button input is ignored when `phase != Phase::Running` (during homing
  or a fault condition).
- Normal operation resumes automatically when `Phase::Running` is published
  by motor_task after homing completes.

## Firmware

### Module: `src/tasks/keys.rs`

`BtnState` tracks per-button debounce with a saturating counter
(`DEBOUNCE_SAMPLES = 2`). `update(pin_low)` returns `true` on any edge
(press or release) and keeps `pressed` reflecting the debounced state.

### Polling Loop

Runs every 20 ms (`Ticker::every(Duration::from_millis(20))`). Each tick:

1. Snapshot `was_jogging` (any jog button held last tick).
2. Update all five debounce counters.
3. Read `Phase` from `STATE`; skip the rest if not `Running`.
4. On CENTER press edge: send `GoTo { az: 0.0, el: 0.0 }`.
5. If any jog button is held: send combined `GoTo` with ±9999 sentinels
   on the active axis and `current_az`/`current_el` on the idle axis.
6. Else if `was_jogging`: send `Stop`.

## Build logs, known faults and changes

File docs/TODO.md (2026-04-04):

# TODO

create a github repo card
add release to github actions
merge to master release a first version
Replace manufacturer Custom to github url
Add screen switch - polar screen, big font - az and el only, info - ip, version, name, github page
Add a beautiful Rust tui companion application to control the rotator
Add a web page written in Rust/wasm as a companion app
Create a few screencasts to promote the app
Create a pitch to show why this project better then others
Use RPico for the same project.
Add real peacture
Create Amazon BOM
    Box Serpac 151 BK
    Base PCB - breadboard 7x9 cm
    Motor drivers
    W5500 module
    Nucleo board
    5 nav joystic
    SSD1306 module
    Power connector
    PoE adaptors
    Standoffs

Schematic
Test Github actions

Add cargo feature for single-axis (AZ-only) build

## Implement 1.5 Rotation

adding overtravel (often called 540° rotation) is a very common and highly effective upgrade for satellite rotators. Allowing 1.5 rotations is exactly how high-end commercial and amateur rotators handle the "dead zone" problem.
Does it help?

Yes, significantly. It reduces the number of "unwinds" you have to perform. If a satellite is crossing your 0° north mark, a standard 360° rotator has to spin all the way around immediately. With a 540° rotator (0° to 540°), you can track that satellite from 350° through 360/0° and all the way to 180° before you ever hit a physical limit.
How to Implement 1.5 Rotation

To make this work, you need to update three layers of your stack:

1. Mechanical & Hardware

    The Cable Loop: Ensure you have a "service loop" (extra slack) in your coax cables. It must be long enough to handle 540° of twist without tensioning the connectors or rubbing against sharp edges.

    Soft Limits: Update your firmware to allow an azimuth range from 0° to 540°.

2. The Logic (The "Overlap")

In this setup, your rotator essentially has "overlapping" degrees.

    0° to 180° is the primary range.

    180° to 360° is the secondary range.

    360° to 540° is the "overlap" range (which physically corresponds to 0° to 180° again).

3. Software (Hamlib / rotctld)

This is the most important step. gpredict doesn't inherently know your rotator can go past 360°. You must configure rotctld (the middleman) with the -m (min azimuth) and -M (max azimuth) flags.

    Example Command:
    rotctld -m 0 -M 540 -model [YOUR_MODEL_ID]

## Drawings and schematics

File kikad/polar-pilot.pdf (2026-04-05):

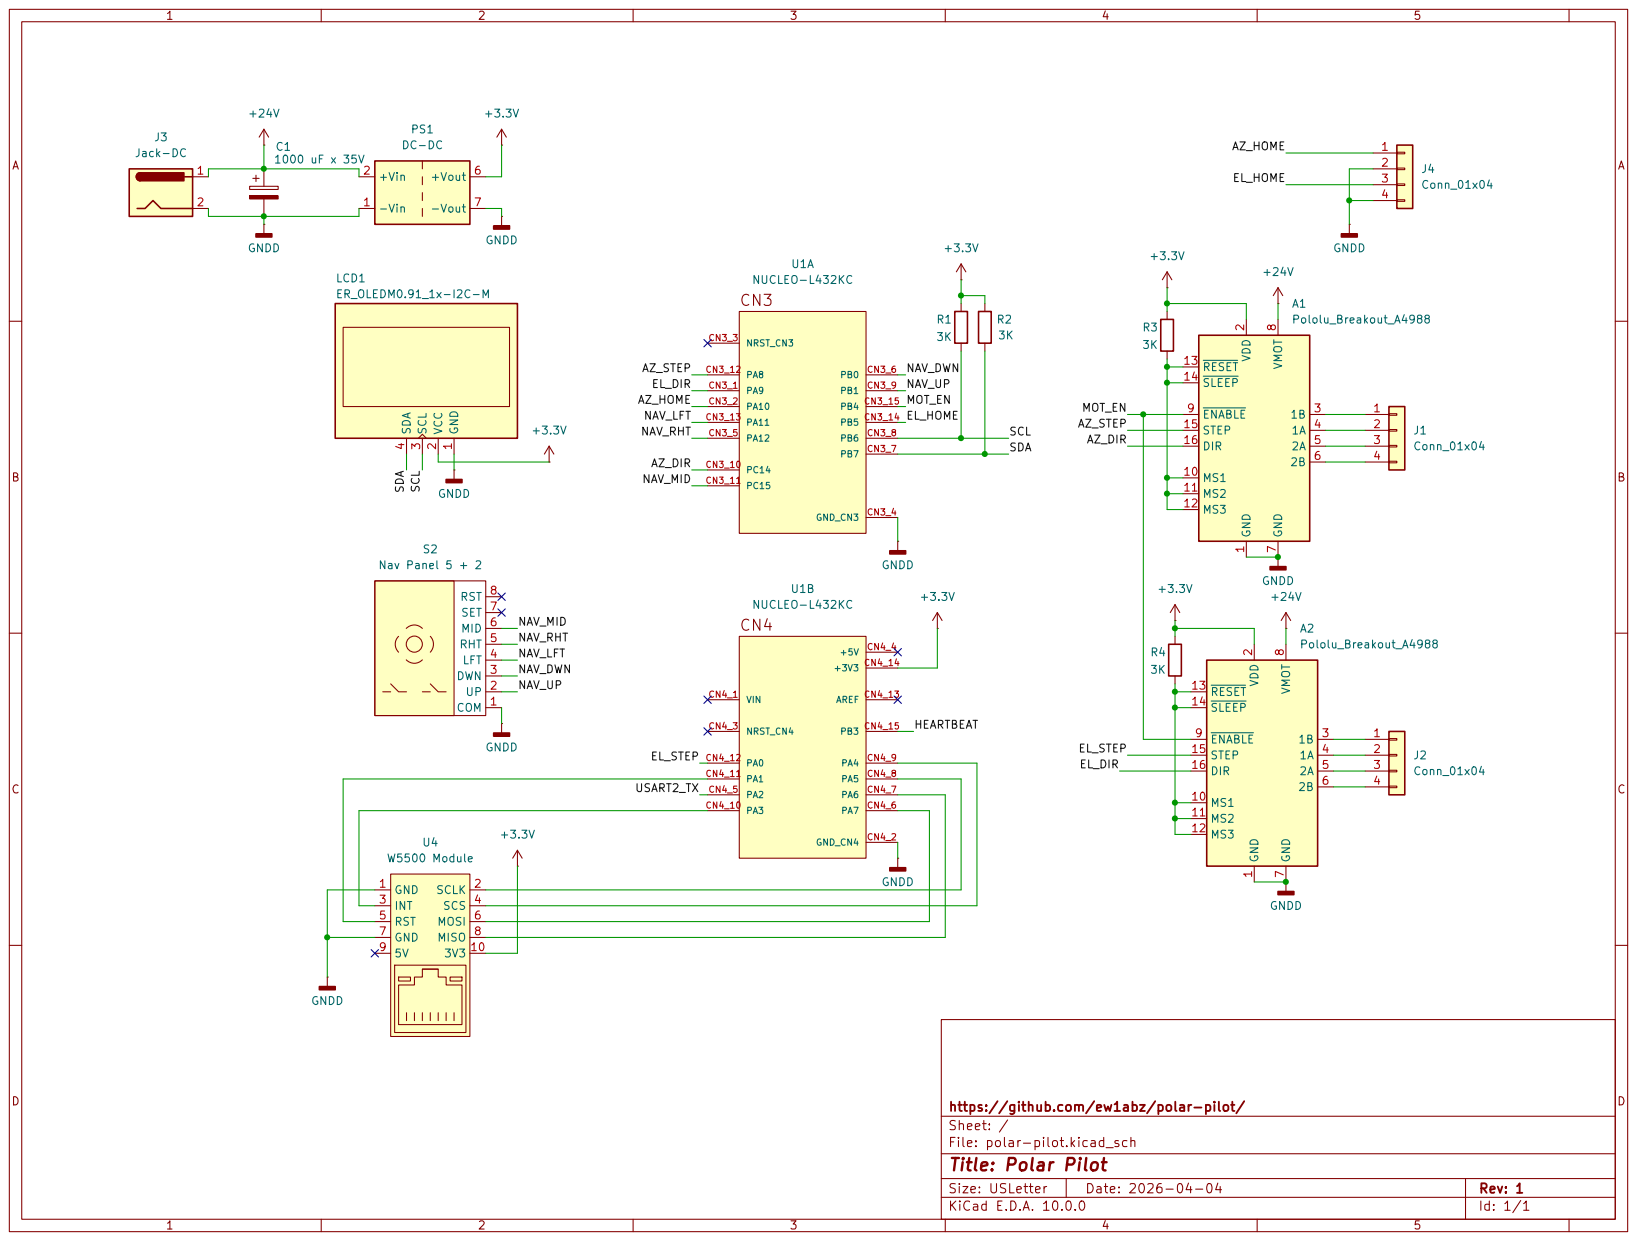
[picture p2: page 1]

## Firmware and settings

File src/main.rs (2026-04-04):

//! Polar Pilot — antenna rotator controller firmware
//!
//! Async tasks on Embassy: motor control, OLED display, 5-way navigation,
//! rotctld TCP server, EasyComm II serial, W5500 Ethernet, heartbeat LED.

#![no_std]
#![no_main]

use defmt::*;
use embassy_executor::Spawner;
use embassy_stm32::exti::ExtiInput;
use embassy_stm32::gpio::{Input, Level, Output, OutputType, Pull, Speed};
use embassy_stm32::i2c::I2c;
use embassy_stm32::spi::{self, Spi};
use embassy_stm32::time::Hertz;
use embassy_stm32::timer::simple_pwm::{PwmPin, SimplePwm};
use embassy_stm32::usart;
use embassy_time::Timer;
use embedded_hal_bus::spi::ExclusiveDevice;
use static_cell::StaticCell;
use {defmt_rtt as _, panic_reset as _};

mod tasks;
mod types;
mod util;

use tasks::display::display_task;
use tasks::easycom::easycom_task;
use tasks::keys::key_task;
use tasks::motor::{motor_task, STEP_HZ};
use tasks::net::{dhcp_watchdog_task, ethernet_task, led_task, net_task};
use tasks::rotctld::rotctld_task;
use types::{RotatorState, STATE};

// ── Interrupt bindings ──────────────────────────────────────────────

embassy_stm32::bind_interrupts!(struct Irqs {
    DMA1_CHANNEL2 => embassy_stm32::dma::InterruptHandler<embassy_stm32::peripherals::DMA1_CH2>;
    DMA1_CHANNEL3 => embassy_stm32::dma::InterruptHandler<embassy_stm32::peripherals::DMA1_CH3>;
    DMA1_CHANNEL6 => embassy_stm32::dma::InterruptHandler<embassy_stm32::peripherals::DMA1_CH6>;
    DMA1_CHANNEL7 => embassy_stm32::dma::InterruptHandler<embassy_stm32::peripherals::DMA1_CH7>;
    EXTI3 => embassy_stm32::exti::InterruptHandler<embassy_stm32::interrupt::typelevel::EXTI3>;
    RNG => embassy_stm32::rng::InterruptHandler<embassy_stm32::peripherals::RNG>;
    USART2 => embassy_stm32::usart::InterruptHandler<embassy_stm32::peripherals::USART2>;
});

// ── Main: init + spawn ──────────────────────────────────────────────

#[embassy_executor::main]
async fn main(spawner: Spawner) -> ! {
    let mut config = embassy_stm32::Config::default();
    {
        use embassy_stm32::rcc::*;
        config.rcc.hsi = true;
        config.rcc.pll = Some(Pll {
            source: PllSource::HSI,
            prediv: PllPreDiv::DIV1,
            mul: PllMul::MUL10,
            divp: None,
            divq: None,
            divr: Some(PllRDiv::DIV2),
        });
        config.rcc.sys = Sysclk::PLL1_R;
        config.rcc.hsi48 = Some(Hsi48Config { sync_from_usb: false });
    }
    let p = embassy_stm32::init(config);

    info!("Polar Pilot starting...");

    // Publish initial state
    STATE.sender().send(RotatorState::default());

    // ── LED heartbeat ───────────────────────────────────────────
    let led = Output::new(p.PB3, Level::High, Speed::Low);
    spawner.spawn(unwrap!(led_task(led)));

    // ── OLED display (I2C1) — spawned after stack so it can read IP ──
    let i2c = I2c::new_blocking(p.I2C1, p.PB6, p.PB7, Default::default());

    // ── W5500 Ethernet (optional) ───────────────────────────────
    let mut w5500_rst = Output::new(p.PA1, Level::Low, Speed::Low);
    Timer::after_millis(1).await;
    w5500_rst.set_high();
    Timer::after_millis(2).await;

    let mut spi_cfg = spi::Config::default();
    spi_cfg.frequency = Hertz(1_000_000);
    let spi = Spi::new(p.SPI1, p.PA5, p.PA7, p.PA6, p.DMA1_CH3, p.DMA1_CH2, Irqs, spi_cfg);
    let cs = Output::new(p.PA4, Level::High, Speed::VeryHigh);
    let spi_dev = ExclusiveDevice::new(spi, cs, embassy_time::Delay).unwrap();

    let w5500_int = ExtiInput::new(p.PA3, p.EXTI3, Pull::Up, Irqs);
    let mac = [0x02, 0x00, 0x00, 0x00, 0x00, 0x01];

    static W5500_STATE: StaticCell<embassy_net_wiznet::State<2, 2>> = StaticCell::new();
    let w5500_state = W5500_STATE.init(embassy_net_wiznet::State::<2, 2>::new());

    let stack = match embassy_net_wiznet::new(mac, w5500_state, spi_dev, w5500_int, w5500_rst).await
    {
        Ok((device, w5500_runner)) => {
            let net_config = embassy_net::Config::dhcpv4(Default::default());
            let mut rng = embassy_stm32::rng::Rng::new(p.RNG, Irqs);
            let seed = rng.next_u32() as u64 | ((rng.next_u32() as u64) << 32);

            static NET_RESOURCES: StaticCell<embassy_net::StackResources<3>> = StaticCell::new();
            let (stack, net_runner) = embassy_net::new(
                device,
                net_config,
                NET_RESOURCES.init(embassy_net::StackResources::new()),
                seed,
            );

            spawner.spawn(unwrap!(ethernet_task(w5500_runner)));
            spawner.spawn(unwrap!(net_task(net_runner)));
            spawner.spawn(unwrap!(dhcp_watchdog_task(stack)));
            spawner.spawn(unwrap!(rotctld_task(stack)));
            spawner.spawn(unwrap!(rotctld_task(stack)));

            info!("W5500 initialized");
            Some(stack)
        }
        Err(_) => {
            warn!("W5500 not found — running without Ethernet");
            None
        }
    };

    spawner.spawn(unwrap!(display_task(i2c, stack)));

    // ── Stepper motors ──────────────────────────────────────────
    let motor_en = Output::new(p.PB4, Level::High, Speed::Low);
    let az_dir = Output::new(p.PC14, Level::Low, Speed::Low);
    let el_dir = Output::new(p.PA9, Level::Low, Speed::Low);
    let az_home = Input::new(p.PA10, Pull::Up);
    let el_home = Input::new(p.PB5, Pull::Up);

    let el_step = PwmPin::new(p.PA0, OutputType::PushPull);
    let el_pwm =
        SimplePwm::new(p.TIM2, Some(el_step), None, None, None, Hertz(STEP_HZ), Default::default());

    let az_step = PwmPin::new(p.PA8, OutputType::PushPull);
    let az_pwm =
        SimplePwm::new(p.TIM1, Some(az_step), None, None, None, Hertz(STEP_HZ), Default::default());

    spawner.spawn(unwrap!(motor_task(az_pwm, el_pwm, az_dir, el_dir, motor_en, az_home, el_home)));

    // ── 5-way navigation buttons ────────────────────────────────
    let btn_up = Input::new(p.PB1, Pull::Up);
    let btn_down = Input::new(p.PB0, Pull::Up);
    let btn_left = Input::new(p.PA11, Pull::Up);
    let btn_right = Input::new(p.PA12, Pull::Up);
    let btn_center = Input::new(p.PC15, Pull::Up);
    spawner.spawn(unwrap!(key_task(btn_up, btn_down, btn_left, btn_right, btn_center)));

    // ── EasyComm II serial (USART2) ─────────────────────────────
    let mut usart_cfg = usart::Config::default();
    usart_cfg.baudrate = 9600;
    let uart =
        usart::Uart::new(p.USART2, p.PA15, p.PA2, p.DMA1_CH7, p.DMA1_CH6, Irqs, usart_cfg).unwrap();
    let (usart_tx, usart_rx) = uart.split();
    spawner.spawn(unwrap!(easycom_task(usart_rx, usart_tx)));

    info!("All tasks spawned");

    // Main task idles
    loop {
        Timer::after_secs(3600).await;
    }
}

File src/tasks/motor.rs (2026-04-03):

use defmt::*;
use embassy_stm32::gpio::{Input, Output};
use embassy_stm32::time::Hertz;
use embassy_stm32::timer::simple_pwm::SimplePwm;
use embassy_time::{with_timeout, Duration, Instant, Timer};

use crate::types::{Phase, RotatorCmd, RotatorState, CMD, LIMITS, STATE};

pub const STEP_HZ: u32 = 4_000;

const STEPS_PER_REV: f32 = 200.0;
const GEAR_RATIO: f32 = 54.0;
const AZ_MICROSTEPS: f32 = 32.0;
const EL_MICROSTEPS: f32 = 32.0; // EL driver MS pins wired for 16; change to 32 if matched
const MOTOR_TICK_MS: u64 = 1;

// Degrees per physical step pulse.
const AZ_DEG_PER_STEP: f32 = 360.0 / (STEPS_PER_REV * AZ_MICROSTEPS * GEAR_RATIO);
const EL_DEG_PER_STEP: f32 = 360.0 / (STEPS_PER_REV * EL_MICROSTEPS * GEAR_RATIO);
// Steps issued per microsecond by the hardware timer.
const STEPS_PER_US: f32 = STEP_HZ as f32 / 1_000_000.0;

const MOTOR_TICK: Duration = Duration::from_millis(MOTOR_TICK_MS);
const POS_EPSILON: f32 = 0.05;

#[embassy_executor::task]
pub async fn motor_task(
    mut az_pwm: SimplePwm<'static, embassy_stm32::peripherals::TIM1>,
    mut el_pwm: SimplePwm<'static, embassy_stm32::peripherals::TIM2>,
    mut az_dir: Output<'static>,
    mut el_dir: Output<'static>,
    mut motor_en: Output<'static>,
    az_home: Input<'static>,
    el_home: Input<'static>,
) -> ! {
    motor_en.set_high(); // disabled

    az_pwm.set_frequency(Hertz(STEP_HZ));
    let max_az = az_pwm.ch1().max_duty_cycle();
    az_pwm.ch1().set_duty_cycle(max_az / 2);
    az_pwm.ch1().disable();

    el_pwm.set_frequency(Hertz(STEP_HZ));
    let max_el = el_pwm.ch1().max_duty_cycle();
    el_pwm.ch1().set_duty_cycle(max_el / 2);
    el_pwm.ch1().disable();

    let state_tx = STATE.sender();
    info!("motor_task: running");

    // Homing constants
    // Back-off: drive positive until endstop releases (or 3 s timeout).
    const BACKOFF_TIMEOUT: Duration = Duration::from_secs(3);
    // Maximum approach travel before declaring a fault.
    const MAX_AZ_HOME_MS: u64 = 95_000; // 380° ÷ ~4°/s
    const MAX_EL_HOME_MS: u64 = 28_000; // 100° ÷ ~4°/s

    // Outer loop: re-entered each time a Home command is received.
    loop {
        // Drain any pending commands so stale GoTo/Stop don't interfere.
        while CMD.try_receive().is_ok() {}

        motor_en.set_low();

        let mut target_az: f32 = 0.0;
        let mut target_el: f32 = 0.0;
        let mut current_az: f32 = 0.0;
        let mut current_el: f32 = 0.0;

        // ── AZ homing ───────────────────────────────────────────────
        info!("motor: homing AZ");

        // Pre-check: if already on endstop, back off until it releases.
        if az_home.is_low() {
            info!("motor: AZ on endstop, backing off");
            az_dir.set_high();
            az_pwm.ch1().enable();
            let result = with_timeout(BACKOFF_TIMEOUT, async {
                loop {
                    if az_home.is_high() {
                        return;
                    }
                    Timer::after(MOTOR_TICK).await;
                }
            })
            .await;
            az_pwm.ch1().disable();
            if result.is_err() || az_home.is_low() {
                motor_en.set_high();
                error!("motor: AZ endstop stuck -- halting");
                state_tx.send(RotatorState {
                    phase: Phase::Fault("AZ endstop stuck"),
                    ..Default::default()
                });
                loop {
                    Timer::after_secs(60).await;
                }
            }
        }

        // Approach home.
        az_dir.set_low();
        az_pwm.ch1().enable();
        let deadline = Instant::now() + Duration::from_millis(MAX_AZ_HOME_MS);
        loop {
            if az_home.is_low() {
                az_pwm.ch1().disable();
                current_az = 0.0;
                target_az = 0.0;
                info!("motor: AZ homed");
                break;
            }
            if Instant::now() > deadline {
                az_pwm.ch1().disable();
                motor_en.set_high();
                error!("motor: AZ travel limit exceeded -- halting");
                state_tx.send(RotatorState {
                    phase: Phase::Fault("AZ travel limit"),
                    ..Default::default()
                });
                loop {
                    Timer::after_secs(60).await;
                }
            }
            state_tx.send(RotatorState {
                target_az,
                target_el,
                current_az,
                current_el,
                moving: true,
                link_up: false,
                phase: Phase::Homing,
            });
            Timer::after(MOTOR_TICK).await;
        }

        // ── EL homing ───────────────────────────────────────────────
        info!("motor: homing EL");

        if el_home.is_low() {
            info!("motor: EL on endstop, backing off");
            el_dir.set_high();
            el_pwm.ch1().enable();
            let result = with_timeout(BACKOFF_TIMEOUT, async {
                loop {
                    if el_home.is_high() {
                        return;
                    }
                    Timer::after(MOTOR_TICK).await;
                }
            })
            .await;
            el_pwm.ch1().disable();
            if result.is_err() || el_home.is_low() {
                motor_en.set_high();
                error!("motor: EL endstop stuck -- halting");
                state_tx.send(RotatorState {
                    phase: Phase::Fault("EL endstop stuck"),
                    ..Default::default()
                });
                loop {
                    Timer::after_secs(60).await;
                }
            }
        }

        el_dir.set_low();
        el_pwm.ch1().enable();
        let deadline = Instant::now() + Duration::from_millis(MAX_EL_HOME_MS);
        loop {
            if el_home.is_low() {
                el_pwm.ch1().disable();
                current_el = 0.0;
                target_el = 0.0;
                info!("motor: EL homed");
                break;
            }
            if Instant::now() > deadline {
                el_pwm.ch1().disable();
                motor_en.set_high();
                error!("motor: EL travel limit exceeded -- halting");
                state_tx.send(RotatorState {
                    phase: Phase::Fault("EL travel limit"),
                    ..Default::default()
                });
                loop {
                    Timer::after_secs(60).await;
                }
            }
            state_tx.send(RotatorState {
                target_az,
                target_el,
                current_az,
                current_el,
                moving: true,
                link_up: false,
                phase: Phase::Homing,
            });
            Timer::after(MOTOR_TICK).await;
        }

        motor_en.set_high();
        info!("motor: homing done");
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

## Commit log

2026-03-22 Initial commit: STM32L432 + W5500 antenna rotator controller
    Embassy-based bare-metal firmware implementing the Hamlib rotctld
    protocol over TCP (port 4533) with DHCP networking. Includes SPI
    test mode (--features test-spi) for hardware debugging.
2026-03-23 Add W5500 driver patches, rotctld module, and docs update
    - embassy-net-wiznet-patch/: local patch fixing integer underflow
    in read_frame(), removing redundant SW reset, combining SPI header
    into single operation
    - src/rotctld.rs: extracted rotctld protocol handler
    - docs/SPEC.md: binary size table, known issues (SPI CLK hi-Z,
    DMA channel mapping)
2026-03-23 Restore W5500 software reset (MR=0x80) in patched driver
    Verified on hardware that the SW reset does not break link detection.
    The original failure was caused by SPI CLK hi-Z corruption, not by
    the reset clearing PHYCFGR. This brings the patch back in line with
    upstream behavior.
2026-03-24 Minimal step signal generator using TIM2_CH1 (PA0) and TIM1_CH1 (PA8)
    Replace W5500 rotctld stub with a bare-bones SimplePwm demo that
    outputs hardware-driven step pulses on the two timer channels.
    Time driver moved from TIM2 to TIM15 to free TIM2 for AZ stepper.
    [main.rs]
2026-03-26 Update spec with full pinout and swap AZ/EL step assignments
    Expand SPEC.md hardware section with complete pin table (sorted by
    Nucleo-32 label) covering all peripherals: W5500 SPI, SSD1306 I2C,
    USART2, stepper STEP/DIR/EN, 5-way nav, endstops, and heartbeat LED.
    Swap AZ/EL step pins to match new spec: AZ STEP on PA8/TIM1_CH1,
    EL STEP on PA0/TIM2_CH1. Move W5500 RST to PA1, EL Home to PB5,
    Nav CENTER to PC15, heartbeat LED on PB3/D13 (onboard LD3).
    [main.rs]
2026-03-27 Add W5500 reset delay, SPI version check, and LED heartbeat task
    Hold RST low for 1 ms and wait 2 ms after release per W5500 datasheet.
    Read VERSIONR in a loop to confirm SPI communication before proceeding.
    Split LED blink into a separate embassy task.
    [main.rs]
2026-03-27 Add hardware test binaries: w5500, button, motor, OLED
    Standalone binaries for testing individual peripherals independently.
    Each test is self-contained with its own main entry point.
2026-03-28 Add endstop homing test, expand firmware to full 9-task rotator
    - Add endstop_test hardware test binary: drives steppers toward
    home at 200 Hz, stops each axis when its endstop triggers
    - Expand main.rs from minimal W5500 demo to full 9-task firmware
    (motor, display, keys, rotctld, easycom, ethernet, net, led)
    - Update CLAUDE.md with complete architecture and pin map
    - Fix docs: add SB1/SB2/SB16/SB18 resistor removal notes, update
    crate table, fix markdownlint errors across all markdown files
    - Add libm dependency for OLED polar display trig functions
    [endstop_test.rs, main.rs]
2026-03-31 Refactor firmware into task modules, switch to panic-reset
    Extract all task logic from main.rs into src/tasks/, src/types.rs,
    src/util.rs. main.rs now only handles clock/peripheral init and spawning.
    Swap panic-probe for panic-reset so the board recovers standalone
    without a debugger attached. Bump version to 0.2.0.
    [display.rs, endstop_test.rs, main.rs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]
2026-03-31 Add reference docs: homing, manual control, user guide, TODO, EEPROM
2026-04-02 Add M/\move command to rotctld
    Jogs azimuth or elevation using the same sentinel GoTo pattern as
    key_task (±9999°), letting motor_task enforce soft limits. Direction
    codes match the Hamlib convention: 2=Up, 4=Down, 8=Left, 16=Right.
    Speed argument is parsed but ignored — motor runs at fixed step rate.
2026-04-02 Add 1/\dump_caps command to rotctld
    Returns the capability block that gpredict and other Hamlib clients
    probe on connect. Includes model metadata, supported operations, and
    current soft limits for AZ/EL range.
2026-04-02 Add R/\reset command to rotctld
    Parks the rotator to 0°/0° on any reset type. No hardware re-homing
    is triggered — a full power cycle is required for that.
2026-04-02 Add w/\send_cmd command to rotctld (stub)
    Returns RPRT -1 — no backend pass-through target exists on this
    firmware. Prevents clients from hanging on an unrecognised command.
2026-04-02 Add rotctld protocol test suite
    Python pytest suite with two layers:
    - tests/stub_server.py in-process TCP stub mirroring the firmware's
    dispatch table, controllable state, no hardware or sleeping needed
    - tests/test_protocol.py 52 stub tests covering all commands, error
    cases, and protocol robustness (pipelining, split segments, CRLF)
    - tests/test_live.py hardware tests gated on ROTATOR_HOST env var,
    covering DHCP connect, motor convergence, stop, reset, limits, and
    two concurrent clients
    - pytest.ini excludes live tests from default run (-m "not live")
    [stub_server.py, test_live.py, test_protocol.py]
2026-04-02 Fix test suite for Python 2 pytest on PATH
    Replace em dashes with -- in test source files (Python 2 rejects
    non-ASCII without an encoding declaration). Switch all invocations to
    python3 -m pytest so the system pytest binary (Python 2) is bypassed.
    Applies to docs/DEVELOPMENT.md and .github/workflows/ci.yml.
    [stub_server.py, test_live.py, test_protocol.py]
2026-04-02 Add EasyComm II live hardware tests
    20 tests covering all commands: VE, ?, AZ/C (query), SA/SE/SA SE,
    AZ<az> EL<el>, W<az> <el>, A<NNN>, E<NNN>, LM get/set, and protocol
    robustness (LF-only, CR-only, sequential queries, unknown commands).
    All tests are @pytest.mark.live; skipped unless ROTATOR_PORT is set.
    Requires pyserial and a USB-serial adapter on USART2 (9600 8N1).
    Motor-movement tests are also @pytest.mark.slow (poll with 60 s deadline).
    Run with:
    ROTATOR_PORT=/dev/ttyUSB0 python3 -m pytest tests/test_easycom.py -v --timeout=60
    [test_easycom.py]
2026-04-02 Fix EasyComm live test reliability on real hardware
    - Module-scoped serial fixture: one connection per test session to avoid
    USART DMA state corruption from repeated port open/close cycles
    - DMA warm-up: 3 VE round-trips after port open to settle the ST-LINK
    VCP before single-byte commands (C, ?) are tested
    - Autouse _drain fixture: clears RX buffer before each test; bumped
    timeout from 50ms to 150ms to catch delayed ST-LINK-buffered bytes
    - recv_pos: retries once on empty readline to handle VCP buffering lag
    - test_keepalive: xfail(strict=False) -- bare-\r response is
    intermittently delayed by the ST-LINK VCP beyond the read window
    - test_az_and_c_agree: xfail -- rapid back-to-back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
    [test_easycom.py]
2026-04-02 Add Home command for forced endstop re-homing
    New RotatorCmd::Home re-runs the full AZ+EL endstop homing sequence.
    motor_task wraps homing + running in an outer loop; Home breaks out of
    the running loop to re-enter it.
    Protocol surface:
    - EasyComm: RH triggers re-home (RS remains soft park to 0/0)
    - rotctld: R 2 triggers re-home (R / R 0 / R 1 remain soft park)
    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
2026-04-02 Fix live test ConnectionRefused: retry _connect and reduce close delay
    rotctld socket recycle (close → accept) takes longer than the ~47 ms
    between back-to-back tests. Two-pronged fix:
    - Reduce post-close delay from 100 ms to 10 ms in rotctld_task
    - _connect() retries up to 20x with 50 ms gaps on ConnectionRefused
    [test_live.py]
2026-04-03 Fix TCP bugs, add ICMP ping, Park command, and test improvements
    TCP / rotctld:
    - Increase heapless::String to 512 and tx_buf to 512 to fix
    truncated dump_caps response (was ~303 bytes, overflowed 256-byte buffer)
    - Add pool_size=2 and spawn rotctld_task twice for 2 concurrent clients
    - Document 2 concurrent client support in SPEC.md
    Firmware:
    - Add RotatorCmd::Park that bypasses soft limits (fixes R command
    parking at az_min instead of 0 when limits were set)
    - Apply Park in both rotctld (R/R0/R1) and easycom (RS)
    - Enable embassy-net auto-icmp-echo-reply for ICMP ping support
    Tests:
    - Add test_icmp_ping to test_live.py
    - Restore default soft limits at end of test_position_clamped_to_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
    [main.rs, motor.rs, test_live.py]
2026-04-03 Remove embassy-net-wiznet-patch (fixes merged upstream, patch was unused)
    Both critical fixes (single SPI transaction header, read_frame bounds
    check) are present in embassy-net-wiznet 0.3.0 on crates.io. The patch
    directory was never wired up via [patch.crates-io] anyway. All 11 live
    tests pass against the upstream crate.
2026-04-04 Add .rustfmt.toml and reformat all sources
    use_small_heuristics = "Max" keeps long function signatures and
    struct initialisers on one line where they fit, reducing noise in
    diffs for the embedded codebase.
    [display.rs, endstop_test.rs, main.rs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]
2026-04-04 Add README, LICENSE (GPL v3), and make W5500 optional at runtime
    - README.md with project overview, hardware table, getting started,
    architecture diagram, and roadmap; includes Polar Pilot logo
    - LICENSE: GNU GPL v3.0
    - W5500 is now optional: embassy_net_wiznet::new() failure is caught
    and logged; ethernet/rotctld tasks are skipped, display_task receives
    Option<Stack> and shows "No ETH" status when absent
    - .markdownlint.json: allow inline HTML (needed for README badges/logo),
    disable MD060 (Unicode pipe alignment false positives)
    [display.rs, main.rs]
2026-04-04 Add GitHub Actions release workflow
    On v*.*.* tags: builds firmware, produces .bin and .hex via
    cargo-objcopy, and publishes a GitHub Release with both files attached.
2026-04-04 Switch repo card from github-readme-stats to gh-card.dev
2026-04-05 Add BOM, KiCad schematic, and expand README features
    - Add docs/BOM.md with 12-row bill of materials including datasheets and
    Amazon links; endstops (missing from TODO list) added as row 6
    - Move polar-pilot.png to docs/ and update README img src
    - Add KiCad schematic (kikad/) and link it from README Hardware section
    - Expand README features: split dual-protocol into dual interface / dual
    serial protocol / dual TCP connection; add soft limits entry
    - Remove docs/MIGRATION_NOTES.md (internal comparison doc, no longer needed)
    [polar-pilot.kicad_sch]
2026-04-05 Expand README and add planning docs
    - Add Quality section: memory safety, two-layer test suite, CI/CD, doc table
    - Expand Roadmap: overtravel (linked), AZ-only build, aux GPIO, OTA, RP2350, custom PCB
    - Add docs/OVERTRAVEL.md: 540° overtravel design notes (not yet implemented)
    - Add docs/RELEASE_CHECKLIST.md: step-by-step release process

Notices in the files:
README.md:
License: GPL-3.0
